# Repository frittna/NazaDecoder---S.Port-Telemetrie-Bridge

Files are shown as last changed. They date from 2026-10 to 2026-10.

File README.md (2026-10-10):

## Naza-M V1/V2 to FrSky SmartPort Telemetry Bridge - Arduino + EDGE-TX LUA SCRIPT
- **Project Site:** https://github.com/frittna/NazaDecoder-S.Port-Telemetrie-Bridge-MPU @ Oct 10, 2026

- -> runterscrollen für detusch - scroll down for german <--

- Integrates all GPS data and compass heading from the DJI Naza-M V1/V2 into the native FrSky SmartPort (S.Port) telemetry data channel.
- Uses the NazaDecoder library https://github.com/dalmirdasilva/ArduinoNazaDecoder and the FrSkySportTelemetry library https://github.com/marhar/FrSkySportTelemetry.
- **Automatically discovered sensors:** Latitude, Longitude, Altitude, Speed, Heading, Timestamp, Satellites\*, FixType\*  
*\*Note: Satellite count and GPS Fix Type are not natively supported in the standard FrSky GPS packet. They are transmitted using auxiliary values via the standard RPM sensor slot (which also contains T1+T2). The RPM sensor itself can be deleted later. Simply rename T1+T2 to "Sats" and "GFix" in your transmitter.*

### Hardware

- **Arduino with ATMega328P 5V:** (This project originally used a repurposed old S-OSD/iOSD REMZIBI module with an onboard Atmega328P, but it will work perfectly fine with any generic Arduino 328P/328PB).
- Requires only one hardware serial input for the GPS signal and one software serial output for the S.Port transmission. An optional LED output can also be used.
- If you use different hardware, you only need to adjust the input/output pin definitions and your preferred programming/flashing settings in the Arduino IDE.

### Wiring / Connections

In my configuration:
- **Atmega328P Pin PD7:** Connect to the SmartPort line via a 1kΩ resistor ("CH3 In THRO" on my S-OSD module).
- **Atmega328P Pin PD0:** Serial RX Pin (PD0 / RXD) connects to the NAZA <-> GPS cable TX line (Pin 2, orange wire next to Pin 1 GND, black).
- **1x Optional Status LED ("Valid Packet Detected"):** Atmega328P Pin 13 / PB1 -> digital Pin 9 in Arduino. (On the S-OSD module: Route the "F1-In" pin to ground through a matching current-limiting resistor and LED).
- **Crucial Note for S-OSD Modules:** If you are repurposing an S-OSD module like me, **do not** loop the GPS signal through the module as originally intended. The "to GPS" and "to LED" pins shown on the module's layout diagram are not directly connected; the internal traces differ from the original reference board.
- You must create a simple tap-off connection for TX and GND directly from the GPS cable. Alternatively, you can desolder unused pins/connectors to build a clean passthrough adapter.
- **OPTIONAL:** For peace of mind, I added a 3.3V to 5V logic level converter for the serial GPS TX signal (3.3V) leading to the Arduino RX (5V). This utilizes a small 3.3V fixed regulator and a level shifter (LV1 to GPS TX, HV1 to Arduino RX).
- **OPTIONAL:** MPU-6000 sensor connection via I²C. This layout integrates directly with my `horz.lua` script. See the LUA script configuration guide below.

### Arduino Programming (Atmega328P)
- **Arduino IDE Settings:** Tools -> Board -> "Arduino Pro or Mini" -> Processor: 16MHz 5V -> Programmer -> STK 500 dev -> Sketch -> Upload Using Programmer (`Ctrl+Shift+U`).
- **When using an ISP cable on the ISP header:** Hold down the BOOT button on the module firmly while flashing.
- *Note:* The Atmega328P has only ONE hardware serial interface. You cannot run the active GPS feed and the serial monitor for debugging at the same time.

---

---

### LUA Script Manual - Attitude & Telemetry Display Script
*Designed for SmartPort Transmitters running EdgeTX @ 2.11.7 or compatible (e.g., Taranis QX7)*

#### Installation
1. Copy all three files (`horz.lua`, `horz_menu.lua`, and `horz_cfg.lua`) into the same folder on your transmitter SD card: `/SCRIPTS/TELEMETRY/`.
2. In your telemetry screen setup page, select only `horz.lua` as the active telemetry script.

#### CONFIG MENU
- `Ground View`: Toggle the ground visualization style between dots, lines, or solid white.
  
- `PITCH/ROLL`: Source adjustments can only be configured in Angle Mode. Otherwise, pitch, roll, and heading can be inverted here.
  
- `HORIZON BOX`: Choose between `FULL` and `LITE`. The Lite mode switches to a simplified, less resource-intensive calculation method for the horizon box boundaries.

#### SENSOR MENU
- Ensure you know the exact names of your telemetry sensors on your radio. In the script's sensor menu, map the sensor `Name` to its corresponding source (`Src`).
- Standard telemetry sensors can be instantly assigned from a scrollable preset list, which auto-fills their units and precision values.
- If a custom sensor is missing from the presets, navigate to page 3 of the sensor menu to register custom entries along with custom units and precision variables.
- **Menu Columns:** `Prec` controls the number of decimal points, `MM` defines a Min/Max threshold value, and the checkbox toggles layout visibility.
- The UI automatically scales down the screen layout (which is quite challenging on monochrome displays) based on whether you display 6 or fewer sensors on the left panel.
- A miniature real-time graph appears if only a single sensor is active on the left sidebar (and the graph checkbox remains enabled in the Config Menu).
- **Threshold Alerts:** If the sensor value moves past the boundary set in `MM`, the current value will appear inverted on the left side while continuing to stream live data. The graph line transitions into a dotted pattern during this state.
- If no custom Min/Max thresholds are configured, the UI simply tracks and displays the session's absolute Min/Max values.
- Disabling the graph causes the single sensor field to display the session minima and maxima text values instead. The horizontal X-axis time window is fully adjustable between 10s and 999s.
- `inside Horizon`: Allows you to display a single floating telemetry value (value + unit only) centered inside the artificial horizon disk. It can be hidden entirely using its visibility checkbox.

#### AXIS MENU
- Select your orientation data input type under `ATTITUDE`.
  - `ANGLES`: Uses standard receiver-calculated angle telemetry (typically `Ptch`/`Roll`).
  - `VECTOR`: Uses normalized accelerometer telemetry (`AccX/Y/Z`). In vector mode, the `fwd`, `side`, and `down` orientations and signs are manually adjustable.
- `Calibrate`: Automatically zeroes out the current orientation offset, provided the correct attitude input type is active.
- *Insight:* A stabilized FrSky receiver generally outputs pre-calculated `Angles`. Separate MPU modules or flight controllers typically output raw or semi-processed gravity `Vectors` (spatial paths where absolute gravity shifts influence the angles). It appears FrSky blends these values internally using their `AccZ` data stream.

#### HORIZON BOX
- `Altimeter-Scale` (Defaults to `Alt`): Adjusts the step increments for the vertical 2.5m / 5m altitude lines on the left side of the horizon container.
- **Home Arrow:** Locks your home coordinates at the first valid 3D GPS fix after the LUA script boots. It displays a dynamic home arrow pointing back toward the launch pad relative to your current heading (`Hdg`). This target tracking indicator is rendered directly onto the visible compass tape.
- **3D View Environment:** Draws distinct dotted attitude indicators at ±45° pitches and dashed reference bars at ±90° limits. The top compass tape also places a dedicated home marker directly onto the sliding scale.
- **Satellite Indicator Widget:** A 10×10px satellite icon sits next to the satellite count on the left.
  - **No Fix:** The icon and text collapse and vanish.
  - **Fix Available:** The base satellite icon begins to flash.
  - **2D/3D Fix:** Dynamic signal waves appear around the icon.
  - **Signal Degradation:** If a solid 3D fix drops back down to a 2D fix, the satellite icon flashes an alert state for 60 seconds, even if the connection restores back to a 3D state during that window.

---

### UI Screenshots & Documentation Gallery

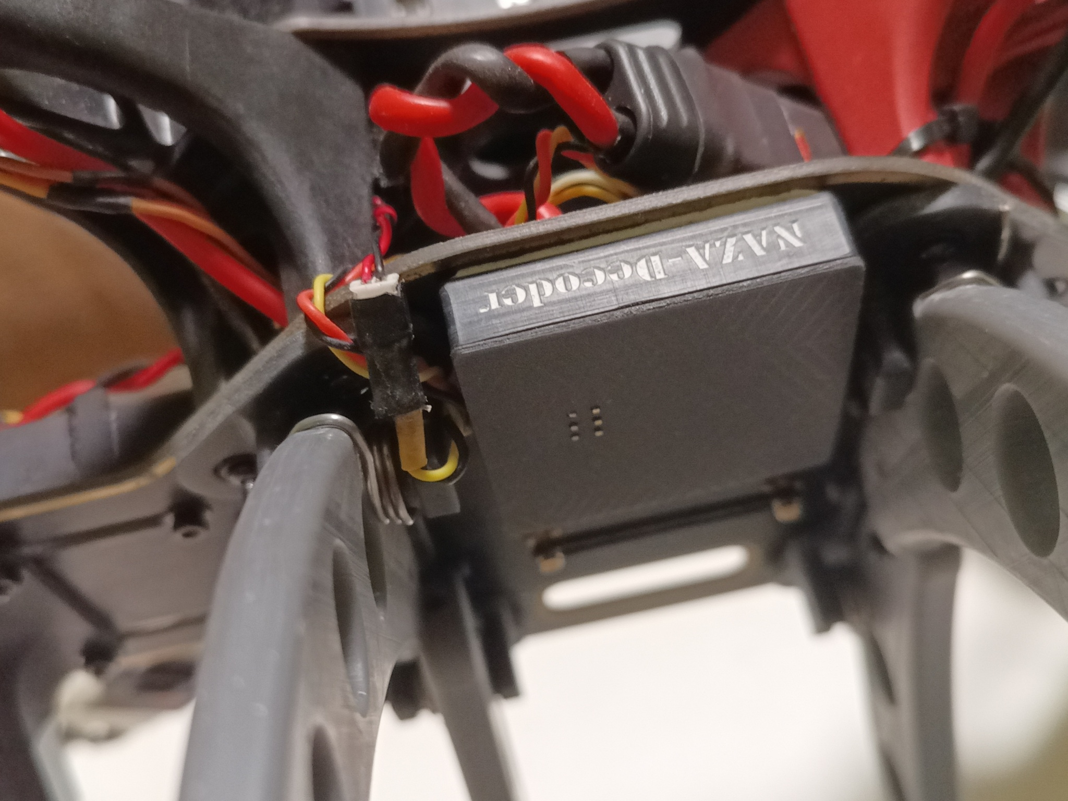
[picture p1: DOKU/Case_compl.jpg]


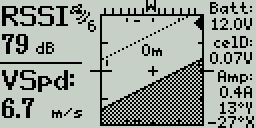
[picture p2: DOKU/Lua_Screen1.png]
 

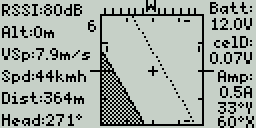
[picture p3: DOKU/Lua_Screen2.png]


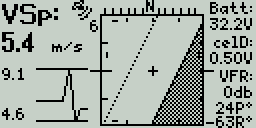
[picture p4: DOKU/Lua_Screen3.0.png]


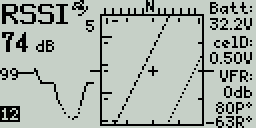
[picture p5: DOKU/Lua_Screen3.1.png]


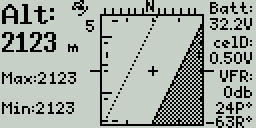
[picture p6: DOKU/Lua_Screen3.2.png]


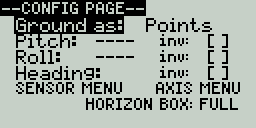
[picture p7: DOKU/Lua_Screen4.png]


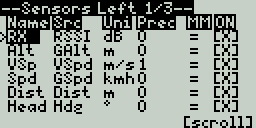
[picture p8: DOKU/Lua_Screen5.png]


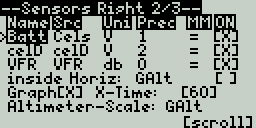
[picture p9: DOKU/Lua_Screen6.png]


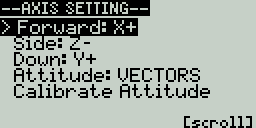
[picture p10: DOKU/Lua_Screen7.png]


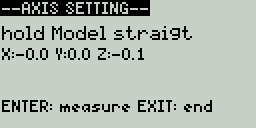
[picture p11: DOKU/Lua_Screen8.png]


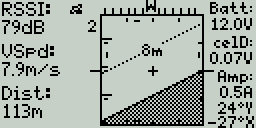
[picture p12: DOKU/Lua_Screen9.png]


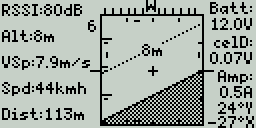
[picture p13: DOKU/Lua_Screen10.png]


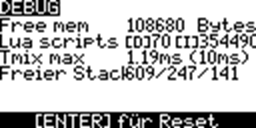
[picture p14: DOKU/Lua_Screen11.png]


---

#########################################################################
#######################################################################
######################################################################
#####################################################################

---

## Naza-M V1/V2 to FrSky SmartPort Telemetrie Bridge - Arduino + EDGE-TX LUA SCRIPT
-  Project Site: https://github.com/frittna/NazaDecoder-S.Port-Telemetrie-Bridge-MPU @ 10.Okt.2026 

- integriert alle GPS-Daten und das Kompass-Heading vom DJI Naza-M V1/V2 in den nativen FrSky SmartPort Telemetrie-Datenkanal S.Port.

- verwendet NazaDecoder Bibliothek https://github.com/dalmirdasilva/ArduinoNazaDecoder und FrSkySportTelemetry Bibiliothek https://github.com/marhar/FrSkySportTelemetry

- automatisch gefundene Sensoren: Latitude, Longitude, Altitude, Speed, Heading, Timestamp, Satellites*, FixType*
*)Die Satellitenanzahl und GPSFix-Type welche im FrSky GPS-Paket nicht vorgesehen sind werden mit Hilfswerten des Standartsensors RPM (enthält auch T1+T2) übertragen. 
RPM selbst kann später gelöscht werden. T1+T2 einfach in "Sats" und GFix" umbenennen.fg

### Hardware

- Arduino mit ATMega328P 5V (hier in Form eines zweckentfremdeten alten S-OSD/iOSD REMZIBI Moduls mit Atmega328P darauf, es wird aber mit jedem Arduino 328P/328PB laufen)
- Es wird nur ein HW-Serial Eingang für das GPS-Singal und ein SW-Serial Port Ausgang für die SPort übertragung gebraucht. Evtl. ein LED-Ausgang.
- Somit ist bei anderer Hardware nur die Pinbelegung des Ein-/Ausgangs anzupassen und evtl. die Einstellungen für den Programmer in Arduino bzw bevorzugte Art es zu flashen.

### Anschlüsse

  In meinem Fall:
- Atmega328P Pin PD7: über R1k Widerstand zu SmartPort Leitung führen ("CH3 In THRO" auf meinem S-OSD Modul). 
- Atmega328P Pin PD0: Serial-RX-Pin (PD0 / RXD) zum NAZA<->GPS Kabel-TX führen (Pin 2 orange, neben 1 GND schwarz).
- 1x Status LED nach Wahl ("gültiges Paket erkannt"): Atmega328P Pin13/PB1 -> 9 in Ardiuono! (am S-OSD Modul: "F1-In"-PIN mit passendem Vorwiderstand über LED nach Masse führen)
- Wenn jemand wie ich dieses umprogrammierte S-ODS Modul verwendet, nicht das GPS wie sonst vorgesehen durch das Modul schleifen. Die Pins des "to GPS" und "to LED" vom Bild des Moduls sind nicht direkt verbunden; die interne Verkabelung ist nicht dieselbe wie beim Original-Board.
- Es muss also vom GPS-Kabel eine einfache Anzapfung für TX und GND gemacht werden, oder viel schöner ist einen Passthrough-Stecker aus den ausgelöteten Stecker und Pins basteln, die man nicht mehr braucht.
- #########
- OPTIONAL: ich habe mir sicherheitshalber einen 3.3V->5V Pegelwandler für das serielle GPS-TX-Signal(3.3V) zum Arduino(5V) eingebaut. Also 3.3V aus kleinem Fix-Regler und 5V in den Levelshifter, mit LV1 zu GPS(TX) und HV1 zu Arduino RX.
- #########
- OPTIONAL: MPU-6000-Senor Anschluß per I²C -> dazu passt auch mein LUA Skript `horz.lua` -> Siehe Anleitung weiter unten im Text..
- #########

### Programmierung des Ardiono bei Atmega328P
- Arduino IDE: Werkzeuge -> Board -> "Arduino Pro or Mini Pro" -> Processor: 16Mhz 5V -> Programmer -> STK 500 dev. -> Sketch -> Programmer upload (Strg+Shift+U)
- ÜBER ISP-KABEL AM ISP ANSCHLUSS -> BOOT BUTTON AM MODUL WÄHREND FLASHEN FEST GEDRÜCKT HALTEN.
- Der Atmega283P hat nur EINE serielle Schnittstelle, aktives GPS und serieller Monitor zum testen gleichzeitig nicht möglich.

---------------------------

---------------------------
### LUA Script Anleitung - Lageanzeige und Telemetie Display Skript - für SmartPort Sender wie Taranis QX9 EdgeTX @ 2.11.7 (und kompatible)
- Dateien / Installation: Alle drei Dateien `horz.lua`, `horz_menu.lua` und `horz_cfg.lua` in denselben Ordner `/SCRIPTS/TELEMETRY/` auf den Sender kopieren.
- Im Screen-Setup wird nur `horz.lua` als Telemetrie-Skript ausgewählt.

### CONFIG MENU
-- `Ground View`: Zeigt Boden als Punkte, Linien oder in weiß

-- `PITCH/ROLL` Source kann nur im Angle-Modus ungestellt werden* , ansonst können diese hier samt Heading invertiert werden.

-- `HORIZON BOX`: FULL/LITE - Lite schaltet auf eine primitivere Berecnungsart der Horizontbox um.

### SENSOR MENU
- Vorher sollte man alle seine Sensornamen vom Sender namentlich 100% kennen und nun im Skipt Menü bei Sensors `Name` und die Quelle `Src` auswählen.
- Sensoren die eher Standaratsensoren sind, können gleich aus der scrollbaren Liste samt Einheit und Präzision zugewiesen werden.
- Wenn ein Sensor nicht in der Liste ist, kann man auf Seite 3 des Sensor-Menüs eigene Sensoren in die Liste eintragen, mit Einheit Präzision.
- Sensorspalte `Prec` ist für die Anzahl der Kommastellen, `MM` für einen MIN/MAX Schwellwert und die Checkbox für die Sichtbarkeit.
- Je nachdem ob auf der Linken Sensorseite 6 oder weniger Werte angezeigt werden, wird versucht die Darstellung auf den Display (ein Krampf) anzupasen.
- Den kleinen Graphen sieht man wenn nur einen Sensor auf der linken Seite aktiv ist (und die Checkbox im Config Menü nicht aus ist).
- Darauf erscheint der aktuelle Wert links invertiert sobald er über oder unter der bei `MM` eingestellten Grenzen liegt und zeigt den Wert weiterhin an. Im Chart ist die Linie dann punktiert.
- Wenn für Sensoren keine MinMax Werte gespeichert wurden, wird einfach das akt. Min/Max der Session angezeigt.
- Ist der Graph deaktiviert, zeigt das Feld mit nur einem Sensorwert stattdessen die Session-Minima und -Maximma. Die Graph X-Time ist einstellbar (10–999s).
- In Horizontmitte lässt sich ein Sensorwert (nur Wert+Einheit) unter `inside Horizon` einstellen und mit Checkbox auch unsichtbar zu machen.
 
### AXIS MENU
- Hier wählt man unter anderem die Art der Lagedaten - `ATTITUDE:` ANGLES (Empfängerwerte meist `Ptch`/`Roll`) oder `VECTOR` (normierte `AccX/Y/Z`). Im Vektormodus sind `fwd`, `side` und `down` samt Vorzeichen einstellbar.
-  `Calibrate` setzt die Ausrichtung automatisch wenn die Eingabeart die richtige gewählt wurde.
-  Ein Frsky Gyro-Empänger liefert mir zb. Angles, der MPU und andere Lagesensoren / FlightController vermutlich auch meist Vektoren, also die Richtungen im Raum und keine Winklel wo die Schwerkraft nicht mitbestimmt.
  (Frsky diese das aber mit ihrer AccZ trotzdem kombiniert meiner Vermutung nach)

### HORIZONT BOX
- `Altimeter-Scale` (Standard `Alt`) steuert die 2,5-m-/5-m-Höhenstriche links an der Horizontbox.
- Der Home-Pfeil wird beim ersten gültigen 3D-Fix nach Lua-Start aus der GPS-Position gesetzt und zeigt relativ zum `Hdg` zur Startposition. Die Richtung wird innerhalb der sichtbaren Kompassskala markiert.
- 3D-View zeigt gepunktete Lage-Linien bei ±45° und gestrichelte Linien bei ±90°; Kompassleiste zeigt auch Homeposition mittels Pfeil auf der Leiste.

- Links der Box wird die Satellitenzahl angezeigt und ein 10×10px großes Satelliten Symbol: ohne GPS-Fix werden Symbol und Zahl ausgeblendet, ab Fix 1 blinkt die Satellitenbasis, bei 2D/3D-Fix kommen Signalstrahlen hinzu.
- Ist ein gültiger 3DFix bereits gefunden und geht auf 2D zurück blinkt der Satellit für 60Sekunden nach, auch wenn wieder auf 3D hochschaltet.

-- Beispiel Bilder: siehe oben

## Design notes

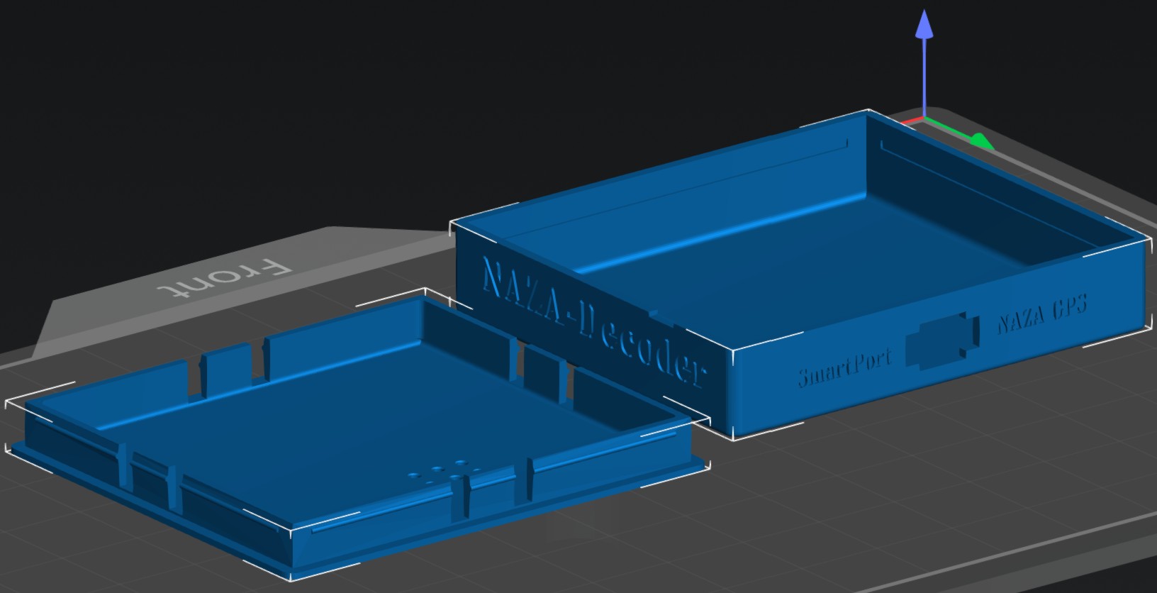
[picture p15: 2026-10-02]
DOKU/Case.jpg

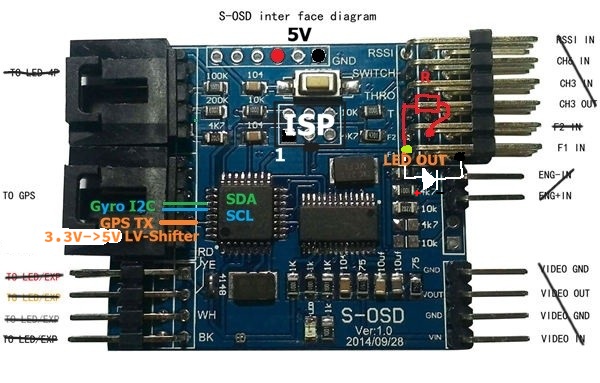
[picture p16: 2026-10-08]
DOKU/s-osd (iosd REMZIBI).jpg

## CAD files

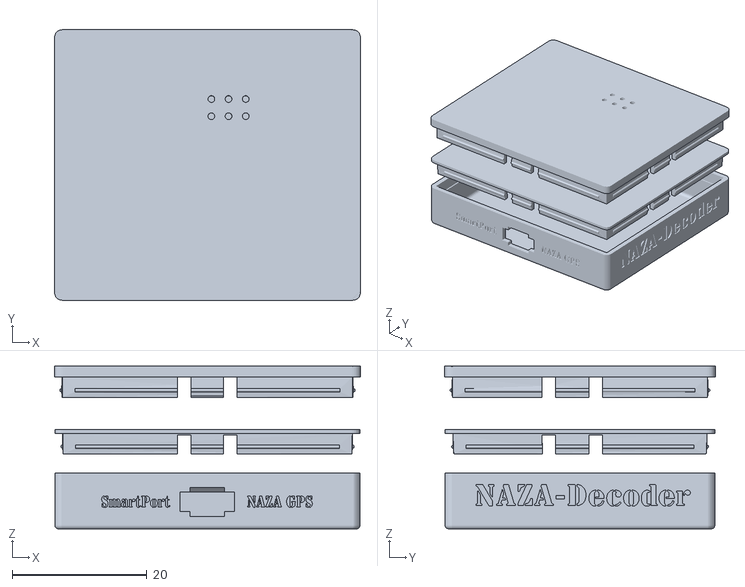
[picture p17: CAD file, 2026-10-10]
DOKU/Case_all.stl
45.4 x 40.1 x 24.1

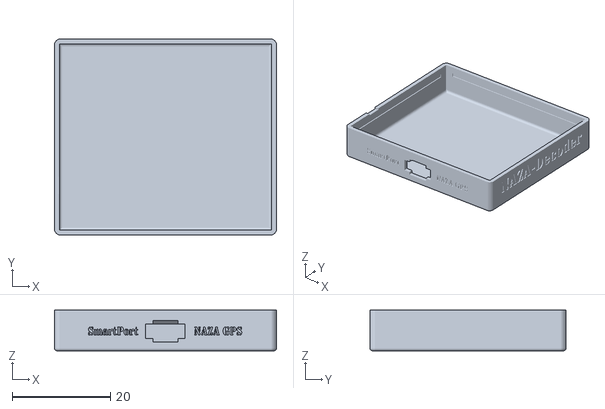
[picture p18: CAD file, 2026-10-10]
DOKU/Case Unterteil.stl
45.2 x 40.0 x 8.30

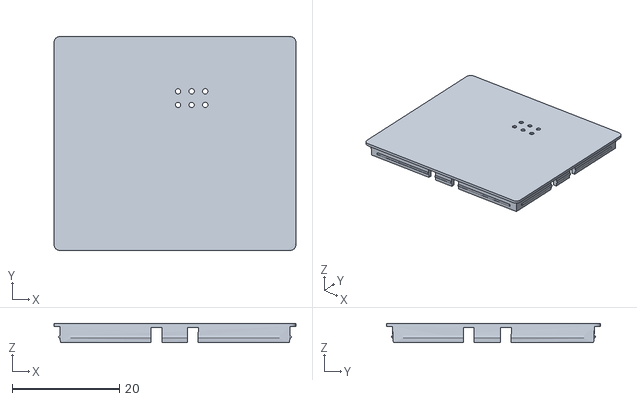
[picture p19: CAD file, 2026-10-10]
DOKU/Case Deckel.stl
45.2 x 40.0 x 3.60

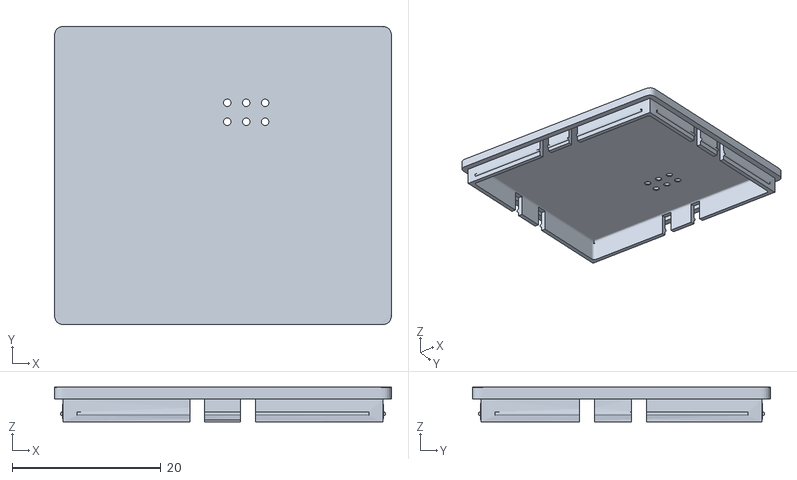
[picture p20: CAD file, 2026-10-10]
DOKU/Case Deckel_hoeher.stl
45.4 x 40.1 x 4.66

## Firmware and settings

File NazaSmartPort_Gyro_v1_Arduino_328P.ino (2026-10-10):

// ****************************************************************************************************************************
// NazaDecoder - S.Port Telemetry Bridge                                                                   @frittna Oct 10, 2026 
// Naza-M V1/V2 to FrSky SmartPort - Arduino
// Integrates all GPS data and compass heading from DJI Naza-M V1/V2 -> to FrSky SmartPort telemetry data channel S.Port.
//                           Version with additional MPU6000/6050 gyro chip for attitude/orientation data
// DEUTSCH:********************************************************************************************************************
// integriert alle GPS Daten und Heading des Kompasses von DJI Naza-M V1/V2 -> zu FrSky SmartPort Telemetrie-Datenkanal S.Port.
//                           Version mit zusätzlichem MPU6000/6050 Gyro-Chip für Lageposition
// ****************************************************************************************************************************
//                                                                                                         

#include <Arduino.h>
#include <math.h>
#include <Wire.h>
#include <FrSkySportSensor.h>
#include <FrSkySportSensorGps.h>
#include <FrSkySportSensorVario.h>
#include <FrSkySportSensorRpm.h>
#include <FrSkySportTelemetry.h>
#include <FrSkySportSingleWireSerial.h>
#include <NazaDecoder.h>

// Montageanpassung: Index 0/1/2 = gX/gY/gZ; Vorzeichen nach Bedarf ändern.
// SPORT-Z folgt dem fusionierten Schwerkraftvektor: bei Modell-Level etwa -1 g.
// Lua-Menü für diesen Gyro-Output: fwd=X+, side=Y+, down=Z- (manuell einstellen).
#define SPORT_X_SOURCE 0
#define SPORT_X_SIGN 1
#define SPORT_Y_SOURCE 1
#define SPORT_Y_SIGN 1
#define SPORT_Z_SOURCE 2
#define SPORT_Z_SIGN 1
// Der Empfänger zeigt bei 100 bisher nur etwa 0,1 g; 1000 liefert den vollen g-Wert.
#define ACC_SPORT_SCALE 1000.0f
#define PITCH_GYRO_SIGN 1
#define ROLL_GYRO_SIGN 1

#undef LED_BUILTIN
#define LED_BUILTIN 9
#define MPU_ADDR 0x68
#define USE_TESTDATA 0
#define SERIAL_MONITOR 0

// Diese SmartPort-IDs bilden die von horz.lua gelesenen AccX/AccY/AccZ-Sensoren.
static const uint8_t ACC_SENSOR_ID = 0x1B;
static const uint16_t ACC_X_DATA_ID = 0x0700;
static const uint16_t ACC_Y_DATA_ID = 0x0710;
static const uint16_t ACC_Z_DATA_ID = 0x0720;

class FrSkySportSensorAccCustom : public FrSkySportSensor {
public:
  FrSkySportSensorAccCustom()
    : FrSkySportSensor((FrSkySportSensor::SensorId)ACC_SENSOR_ID),
      accXData(0), accYData(0), accZData(0), sendStage(0) {}

  void setData(float accX, float accY, float accZ) {
    accXData = (int32_t)(accX * ACC_SPORT_SCALE);
    accYData = (int32_t)(accY * ACC_SPORT_SCALE);
    accZData = (int32_t)(accZ * ACC_SPORT_SCALE);
  }

  virtual uint16_t send(FrSkySportSingleWireSerial& serial, uint8_t id, uint32_t now) {
    (void)now;
    if (id != sensorId) return 0;
    switch (sendStage) {
      case 0:
        serial.sendData(ACC_X_DATA_ID, accXData);
        sendStage = 1;
        return ACC_X_DATA_ID;
      case 1:
        serial.sendData(ACC_Y_DATA_ID, accYData);
        sendStage = 2;
        return ACC_Y_DATA_ID;
      default:
        serial.sendData(ACC_Z_DATA_ID, accZData);
        sendStage = 0;
        return ACC_Z_DATA_ID;
    }
  }

private:
  int32_t accXData, accYData, accZData;
  uint8_t sendStage;
};

FrSkySportSensorGps gpsSensor;
FrSkySportSensorVario varioSensor;
FrSkySportSensorRpm rpmSensor;
FrSkySportSensorAccCustom gyroSensor;
FrSkySportTelemetry telemetry;
NazaDecoder naza;

static const uint32_t GYRO_WARMUP_TIME = 25000UL;
static const uint32_t MPU_UPDATE_INTERVAL = 40UL;
static uint32_t systemStartTime = 0;
static uint32_t warmupCompleteLedStart = 0;
static uint32_t ledPulseStart = 0;
static uint32_t lastUpdate = 0;
static uint32_t lastFilterTime = 0;
static float gyroBiasX = 0.0f;
static float gyroBiasY = 0.0f;
static float gyroBiasSumX = 0.0f;
static float gyroBiasSumY = 0.0f;
static uint16_t gyroBiasSamples = 0;
// Nach 25 s Aufwärmen folgen 25 Messungen (ca. 1 s) zur Gyro-Offsetbestimmung.
static const uint16_t GYRO_BIAS_SAMPLE_COUNT = 25;
static const uint32_t LED_PULSE_DURATION = 50UL;
static const uint32_t WARMUP_LED_DURATION = 1500UL;
static bool gyroBiasReady = false;
static bool angleInitialized = false;
static float anglePitch = 0.0f;
static float angleRoll = 0.0f;

#if USE_TESTDATA == 1
float dummyLatitude = 48.8584f;
float dummyLongitude = 2.2945f;
float dummyAltitude = 100.5f;
float dummySpeed = 5.5f;
float dummyCourse = 45.0f;
float dummyVertSpeed = 1.2f;
uint8_t dummySatellites = 9;
uint8_t dummyFixType = 3;
uint8_t dummyYear = 26;
uint8_t dummyMonth = 9;
uint8_t dummyDay = 26;
uint8_t dummyHour = 14;
uint8_t dummyMinute = 35;
uint8_t dummySecond = 0;
#endif

static void writeMpuRegister(uint8_t reg, uint8_t value) {
  Wire.beginTransmission(MPU_ADDR);
  Wire.write(reg);
  Wire.write(value);
  Wire.endTransmission(true);
}

static int16_t readMpuWord() {
  const uint16_t highByte = (uint8_t)Wire.read();
  const uint16_t lowByte = (uint8_t)Wire.read();
  return (int16_t)((highByte << 8) | lowByte);
}

static float wrapAngle(float angle) {
  while (angle > 180.0f) angle -= 360.0f;
  while (angle < -180.0f) angle += 360.0f;
  return angle;
}

void setup() {
  pinMode(LED_BUILTIN, OUTPUT);
  digitalWrite(LED_BUILTIN, HIGH);
  delay(130);
  digitalWrite(LED_BUILTIN, LOW);
  delay(130);
  digitalWrite(LED_BUILTIN, HIGH);
  delay(130);
  digitalWrite(LED_BUILTIN, LOW);
  delay(500);

  Serial.begin(115200);
  Wire.begin();
  Wire.setClock(400000);
  writeMpuRegister(0x6B, 0x00);  // MPU aufwecken
  writeMpuRegister(0x1C, 0x00);  // Beschleunigung: +/-2 g (16384 LSB/g)
  writeMpuRegister(0x1B, 0x00);  // Gyro: +/-250 Grad/s (131 LSB/(Grad/s))

  telemetry.begin(
    FrSkySportSingleWireSerial::SOFT_SERIAL_PIN_7,
    &gpsSensor, &varioSensor, &rpmSensor, &gyroSensor);

  systemStartTime = millis();
  lastFilterTime = systemStartTime;
  lastUpdate = systemStartTime;
  Serial.flush();
}

void loop() {
#if USE_TESTDATA == 0
  while (Serial.available() > 0) {
    uint8_t msgType = naza.decode(Serial.read());
    if (msgType == NazaDecoder::NAZA_MESSAGE_GPS_TYPE) {
      rpmSensor.setData(0, (float)naza.getSatellites(), (float)naza.getFixType());
      const float latitude = naza.getLatitude();
      const float longitude = naza.getLongitude();
      const float altitude = naza.getAltitude();
      if (naza.getFixType() >= 2 && isfinite(latitude) && isfinite(longitude) &&
          isfinite(altitude) && fabs(latitude) <= 90.0f && fabs(longitude) <= 180.0f &&
          altitude <= 3000.0f) {
        gpsSensor.setData(latitude, longitude, altitude, naza.getSpeed(), naza.getHeading(),
                          naza.getYear(), naza.getMonth(), naza.getDay(), naza.getHour(),
                          naza.getMinute(), naza.getSecond());
        varioSensor.setData(altitude, naza.getVerticalSpeedIndicator());
      }
      digitalWrite(LED_BUILTIN, HIGH);
      ledPulseStart = millis();
    }
  }
#endif

  const uint32_t now = millis();
  if (ledPulseStart > 0 && now - ledPulseStart >= LED_PULSE_DURATION) {
    if (warmupCompleteLedStart == 0 || now - warmupCompleteLedStart >= WARMUP_LED_DURATION) {
      digitalWrite(LED_BUILTIN, LOW);
      ledPulseStart = 0;
    }
  }
  if (warmupCompleteLedStart > 0 && now - warmupCompleteLedStart >= WARMUP_LED_DURATION) {
    digitalWrite(LED_BUILTIN, LOW);
    warmupCompleteLedStart = 0;
  }

  if (now - lastUpdate >= MPU_UPDATE_INTERVAL &&
      (uint32_t)(now - systemStartTime) >= GYRO_WARMUP_TIME) {
    lastUpdate = now;
    Wire.beginTransmission(MPU_ADDR);
    Wire.write(0x3B);
    Wire.endTransmission(false);
    Wire.requestFrom(MPU_ADDR, (uint8_t)14, (uint8_t)true);
    if (Wire.available() >= 14) {
      const int16_t accRawX = readMpuWord();
      const int16_t accRawY = readMpuWord();
      const int16_t accRawZ = readMpuWord();
      const int16_t tempRaw = readMpuWord();
      const int16_t gyroRawX = readMpuWord();
      const int16_t gyroRawY = readMpuWord();
      const int16_t gyroRawZ = readMpuWord();
      (void)tempRaw;
      (void)gyroRawZ;

      const float accX = (float)accRawX / 16384.0f;
      const float accY = (float)accRawY / 16384.0f;
      const float accZ = (float)accRawZ / 16384.0f;
      const float accPitch = atan2f(-accX, sqrtf(accY * accY + accZ * accZ)) * 57.2957795f;
      const float accRoll = atan2f(accY, accZ) * 57.2957795f;
      const uint32_t filterNow = millis();
      const float dt = (float)(filterNow - lastFilterTime) / 1000.0f;
      lastFilterTime = filterNow;

      if (!gyroBiasReady) {
        // Das Modell während dieser Offsetmessung unbedingt ruhig halten.
        gyroBiasSumX += (float)gyroRawX;
        gyroBiasSumY += (float)gyroRawY;
        gyroBiasSamples++;
        if (gyroBiasSamples >= GYRO_BIAS_SAMPLE_COUNT) {
          gyroBiasX = gyroBiasSumX / gyroBiasSamples;
          gyroBiasY = gyroBiasSumY / gyroBiasSamples;
          gyroBiasReady = true;
          warmupCompleteLedStart = filterNow;
          digitalWrite(LED_BUILTIN, HIGH);
        }
      }

      if (!angleInitialized || dt <= 0.0f || dt > 0.25f) {
        anglePitch = accPitch;
        angleRoll = accRoll;
        angleInitialized = true;
      } else if (!gyroBiasReady) {
        // Während der Bias-Messung nur Acc-Winkel nutzen, keinen ungeeichten Gyro integrieren.
        anglePitch = accPitch;
        angleRoll = accRoll;
      } else {
        const float gyroPitchRate = (((float)gyroRawY - gyroBiasY) / 131.0f) * PITCH_GYRO_SIGN;
        const float gyroRollRate = (((float)gyroRawX - gyroBiasX) / 131.0f) * ROLL_GYRO_SIGN;
        const float alpha = 0.98f;
        anglePitch = alpha * (anglePitch + gyroPitchRate * dt) + (1.0f - alpha) * accPitch;
        const float rollAccNearest = angleRoll + wrapAngle(accRoll - angleRoll);
        angleRoll = wrapAngle(alpha * (angleRoll + gyroRollRate * dt) +
                              (1.0f - alpha) * rollAccNearest);
      }

      const float pitchRad = anglePitch * 0.01745329252f;
      const float rollRad = angleRoll * 0.01745329252f;
      // Fusion erzeugt die kanonische Schwerkraft mit negativem Z bei Modell-Level.
      const float gravity[3] = {
        -sinf(pitchRad),
        sinf(rollRad) * cosf(pitchRad),
        -cosf(rollRad) * cosf(pitchRad)
      };
      const float outX = gravity[SPORT_X_SOURCE] * SPORT_X_SIGN;
      const float outY = gravity[SPORT_Y_SOURCE] * SPORT_Y_SIGN;
      const float outZ = gravity[SPORT_Z_SOURCE] * SPORT_Z_SIGN;
      gyroSensor.setData(outX, outY, outZ);
    }
  }

#if USE_TESTDATA == 1
  static uint32_t loopCount = 0;
  static uint32_t lastTestUpdate = 0;
  if (now - lastTestUpdate >= 40UL) {
    lastTestUpdate = now;
    loopCount++;
    const float speedVariation = dummySpeed + sinf(loopCount / 10.0f) * 0.5f;
    const float altVariation = dummyAltitude + sinf(loopCount / 20.0f) * 5.0f;
    const float vertSpeedVariation = dummyVertSpeed + cosf(loopCount / 15.0f) * 0.3f;
    gpsSensor.setData(dummyLatitude, dummyLongitude, altVariation, speedVariation, dummyCourse,
                      dummyYear, dummyMonth, dummyDay, dummyHour, dummyMinute, dummySecond);
    varioSensor.setData(altVariation, vertSpeedVariation);
    rpmSensor.setData(0, (float)dummySatellites, (float)dummyFixType);
    if (ledPulseStart == 0) {
      digitalWrite(LED_BUILTIN, HIGH);
      ledPulseStart = now;
    }
  }
#endif

#if SERIAL_MONITOR == 1
  static uint32_t lastDebug = 0;
  if (now - lastDebug >= 500UL) {
    lastDebug = now;
    Serial.print(F("Pitch="));
    Serial.print(anglePitch, 1);
    Serial.print(F(" Roll="));
    Serial.println(angleRoll, 1);
  }
#endif
  telemetry.send();
}

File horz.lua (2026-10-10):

-- ======================================================================================================================
-- LUA: Horizon & Telemetry Sensor Display for FrSky Sensors (QX7 - EdgeTX 2.10/2.11 BW Display) -- @frittna Oct 10, 2026 
-- ======================================================================================================================
--> This LUA script was created during the project: github.com/frittna/NazaDecoder-S.Port-Telemetrie-Bridge-MPU
--> Files (all three must be placed in the same directory under /SCRIPTS/TELEMETRY/ on your transmitter):
-->   horz.lua       Main view (this is the actual telemetry script, select only this one in your screen setup)
-->   horz_menu.lua  Menu/Calibration/Config-Editor (loaded only upon a long press of the MENU button)
-->   horz_cfg.lua   Config load/save + Sensor catalog (loaded dynamically and briefly when needed)
--> The auxiliary files have names longer than 6 characters and are loaded via loadScript() using their full
--> path. If they appear in your telemetry script selection menu: adjust the path in DIR and move both
--> auxiliary files into a subfolder (e.g., /SCRIPTS/TELEMETRY/horz/).

--DEUTSCH:
-- LUA: Horizont & Telemetrie Sensor Display for FrSky Sensoren (QX7 - EdgeTX 2.10/2.11 BW Display) -- @frittna 10.Okt.2026
--> Das LUA Script ist entstanden beim Projekt github.com/frittna/NazaDecoder-S.Port-Telemetrie-Bridge-MPU
--> Dateien (alle drei im selben Ordner /SCRIPTS/TELEMETRY/ auf dem Sender):
-->   horz.lua       Hauptansicht (das ist das Telemetry-Script, nur dieses im Screen-Setup waehlen)
-->   horz_menu.lua  Menue/Kalibrierung/Config-Editor, wird erst bei langem MENU-Druck geladen
-->   horz_cfg.lua   Config laden/speichern + Sensor-Katalog, wird nur kurz geladen
--> Die Nebendateien haben mehr als 6 Zeichen im Namen und werden per loadScript() mit vollem
--> Pfad geladen. Falls sie in der Telemetry-Script-Auswahl auftauchen: Pfad in DIR anpassen und
--> beide in einen Unterordner legen (z.B. /SCRIPTS/TELEMETRY/horz/).

--SKRIPT--

local DEBUG_MEM = false -- true: zeigt collectgarbage("count") in KB (jetzt/Spitze/nach init)
local DIR = "/SCRIPTS/TELEMETRY/"
local SLOT_COUNT, STANDARD_SLOT_COUNT = 15, 9
local CUSTOM_SLOT_FIRST = STANDARD_SLOT_COUNT + 1
local SLOT_NAME_VISIBLE = 4
local SPARK_N = 40
local SPARK_LABEL_CHAR_WIDTH, SPARK_LABEL_PAD = 5, -1 -- SMLSIZE character width and spacing in pixels
local SPARK_LABEL_X, SPARK_LABEL_HEIGHT = 0, 6
local SPARK_MIN_PLOT_WIDTH = 4
local SPARK_LABEL_COMPACT_DIGITS = 6
local ALTITUDE_TICK_METERS, ALTITUDE_METERS_PER_HALFBOX = 2.5, 5
-- Der Durchmesser enthaelt den Faktor 2 der Haversine-Distanz.
local EARTH_MEAN_DIAMETER_METERS = 12742000
local HOME_MIN_DISTANCE_METERS, COMPASS_PIXELS_PER_DEGREE = 5, 0.75
local DEGREE_UTF8 = "°"
local atan2 = math.atan2 or function(y, x)
    if x > 0 then return math.atan(y / x) end
    if x < 0 then return math.atan(y / x) + ((y >= 0) and math.pi or -math.pi) end
    if y > 0 then return math.pi / 2 end
    if y < 0 then return -math.pi / 2 end
    return 0
end

-- Gemeinsamer Zustand fuer Hauptansicht, Menue und Config-Modul
local cfg = {
    dir = DIR,
    invPitch = 0, invRoll = 0, invHdg = 0,
    groundMode = 2, attitudeMode = 1, viewMode = 1,
    pitchSource = "Ptch", rollSource = "Roll",
    insideSource = "Alt", insideEnabled = 1,
    altimeterSource = "Alt",
    graphSeconds = 30, graphEnabled = 1,
    fwdAxis = "X+", sideAxis = "Z-", downAxis = "Y+",
    sName = {}, sSrc = {}, sUnit = {}, sOn = {},
    sPrecision = {}, sMin = {}, sMax = {},
    configSaveFailed = false, configLoadWarning = false
}
local sMin, sMax = cfg.sMin, cfg.sMax
local menu, menuFailUntil = nil, 0
local ready, dirty = false, false
local memInit, memPeak = 0, 0

-- Vorberechnete Werte (nur in prepare() neu gesetzt)
local invPitch, invRoll, invHdg = 0, 0, 0
local groundMode, attitudeMode, viewMode = 2, 1, 1
local pitchSrc, rollSrc, altSrc, insideSrc = "", "", "", ""
local insideEnabled, insideFmt, insideIsAlt = 1, "%.1f", true
local graphEnabled, graphInterval = 1, 0
local axI, axS = { 1, 2, 3 }, { 1, 1, 1 }
local pSrc, pName, pLabel, pUnit, nameLen, uLen = {}, {}, {}, {}, {}, {}
local valFmt, fmtBoth, fmtLine, fmtMax, fmtMin = {}, {}, {}, {}, {}
local track, pShow = {}, {}
local leftActive, leftN, leftStep = {}, 0, 0
-- Werte und Texte, nur bei Wertaenderung neu formatiert
local slotValues, lastVal = {}, {}
local valText, bothText, lineText, vLen, bLen = {}, {}, {}, {}, {}

local sessionMin, sessionMax, sessionSource = {}, {}, {}
local sparkBuf, sparkCount, sparkHead, sparkLast, sparkSlot, sparkSrc, sparkInterval =
    {}, 0, 0, 0, 0, nil, 0
local filteredAlt, filteredHdg = 0, 0
local homeLat, homeLon
local gpsFix3Since, gpsLowFixSince, gpsWarningSince = nil, nil, nil
local vec = { 0, 0, 0 }

local headingLabels = {
    [0] = "N",
    [45] = "NO",
    [90] = "O",
    [135] = "SO",
    [180] = "S",
    [225] = "SW",
    [270] = "W",
    [315] = "NW"
}

local function isFinite(value)
    return value and value == value and value ~= math.huge and value ~= -math.huge
end

-- Zeichenzahl (das UTF-8-Gradzeichen zaehlt als 1), ohne Tabellen zu erzeugen
local function charLen(text)
    local count, at = #text, 1
    while true do
        local found = string.find(text, DEGREE_UTF8, at, true)
        if not found then return count end
        count, at = count - 1, found + 2
    end
end

local function escapeFormat(text)
    return (string.gsub(text, "%%", "%%%%"))
end

local function axisSetting(k, setting)
    local axis = string.sub(setting, 1, 1)
    axI[k] = (axis == "X") and 1 or ((axis == "Y") and 2 or 3)
    axS[k] = (string.sub(setting, 2, 2) == "-") and -1 or 1
end
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

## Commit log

2026-10-03 Rename Case compl.jpg to Case_compl.jpg
2026-10-03 Add files via upload
    MPU-6000/MPU-6500 Gyro inegration
2026-10-03 Gyro integration MPU6000/MPU6500
2026-10-03 Update NazaSmartPort_Gyro_Arduino_328P.ino_optional
    Gyro integration MPU6000/MPU6500
2026-10-04 added optional Gyro support MPU6000/MPU6500
2026-10-05 added optional Gyro support MPU6000/MPU6500
    add axis mapping and sensor mapping menu
2026-10-05 Horizon and Sensor Display - Lua Skript
    added axis mapping and sensor mapping menu
    save state depending on modelname in LOGS folder
2026-10-05 Horizon and Sensor Display Lua Skript
    added axis mapping menu
    added sensor mapping and custom units
    seperate settings file depending on model name
2026-10-05 added Horizon and Sensor Display LUA for Taranis QX7
    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
2026-10-06 added optional Gyro support MPU6000/MPU6500
    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
2026-10-06 added optional Gyro support MPU6000/MPU6500
    Bugfixes
    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
    [horz.lua]
2026-10-06 Horizon and Sensor Display LUA Skript - QX7 Edge-TX 2.11
    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
    [horz.lua]
2026-10-07 Add dual attitude modes and fused MPU output
2026-10-07 Document attitude modes and validate calibration
2026-10-07 Read MPU samples safely on AVR
2026-10-07 Rename gyro sketch as standalone v1
2026-10-07 Show calibration feedback when sensor data is missing
    [horz.lua]
2026-10-07 Make vector calibration scale-independent
2026-10-07 Fix menu handler branch closure
    [horz.lua]
2026-10-07 Avoid menu overlap and redundant writes
    [horz.lua]
2026-10-07 Correct optional gyro sketch README path
2026-10-07 Clarify empty sensor handling
2026-10-07 Support full editable slot labels
2026-10-07 Harden sensor config parsing
2026-10-07 Report incompatible legacy config
    [NazaSmartPort_Gyro_v1_Arduino_328P.ino, horz.lua]
2026-10-07 Read config completely and document gyro axes
2026-10-07 Move Ground to first menu row
2026-10-07 Fix config loading and menu cosmetics
    [horz.lua]
2026-10-07 Calibrate MPU after warm-up
2026-10-07 Add fix-aware satellite glyph
    [horz.lua]
2026-10-07 Add quick skip for menu edit fields
    [horz.lua]
2026-10-07 Add GAlt to sensor catalog
2026-10-07 Add home bearing pointer to horizon
2026-10-07 Correct bearing direction toward home
    [horz.lua]
2026-10-08 Apply requested menu layout and source fixes
    [horz.lua]
2026-10-08 Fix menu source separation and polish
    [horz.lua]
2026-10-08 much better und less bugs
    [horz.lua]
2026-10-08 Fix 3D view branch structure
    [horz.lua]
2026-10-08 added optional Gyro support MPU6000/MPU6500
    Updated comments for clarity and added version information.
2026-10-09 added graph and variable sensor field feature
    sensor filds and their font sizes are now adjusted automatically depending on how many sensors are active. (on the left side!)
    1 sensor enables the visualization of a simple graph fied of that sensor. X-Time is adjustable from 0-999s.
2026-10-10 cleaned up menu and sensor list, custom names, graph min/max
2026-10-10 Split horz.lua into main view, menu and config modules to fix QX7 "script panic: out of memory" (#4)
    * Initial plan
    * Split horz.lua into main view, menu and config lua files; remove per-frame allocations
    * Remove duplicate option
    Commented out duplicate options in the menu.
    * Update horz_menu.lua
    * Update horz_menu.lua
    * Menu: remove duplicate Attitude from config page and BOX from axis page
    * Apply remaining changes
    ---------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
    [horz.lua]
2026-10-10 horz.lua: invertierte Ueberschreitung von MM-Grenzen im Sensorgraph, Graph 1px links, rechts +3px, Label-Abstand -3px
2026-10-10 README: final wording for MM graph behavior and related sensor graph description
2026-10-10 horz.lua: remove right-side limit text; keep session extreme inverted at left and scale graph with it (runtime only)
    [horz.lua]
